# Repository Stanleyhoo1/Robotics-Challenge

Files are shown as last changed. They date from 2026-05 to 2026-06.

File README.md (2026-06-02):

# Robotics-Challenge

All active firmware lives in `main/`. Top-level companion folders:

| Folder | Purpose |
|---|---|
| `main/` | **Final firmware** — multi-file Arduino sketch |
| `docs/` | Software architecture diagrams and Mermaid flowcharts |
| `testing/` | Standalone test sketches (`line_following`, `motor_test`, `encoder_test`, `turn_test`, `junction_test`, `servo_motor`, `wifi`, `i2c_scan`) and the Testing & Calibration evidence PDF |
| `grid_nav_test/` | Integration test: line-zone grid navigation with RFID |
| `grid_nav_no_line_test/` | Integration test: no-line-zone dead-reckoning |
| `obstacle_avoid_test/` | Integration test: obstacle detection and A\* rerouting |
| `robot_revival_test/` | Integration test: multi-robot revival mechanic |
| `WallFollowing/` | Isolated wall-following development sketch |

## Repository structure

```
main/
├── main.ino           setup() / loop(); owns showIR, showDistance, showEncoders,
│                      showPitch, showLDR, isEnabled, useStateMachine,
│                      lastForwardDistanceCm; power-button + obstacle gates
├── config.h           tunable constants — pins, speeds, gains, thresholds,
│                      calibration values, airlock coords, line-zone split
├── globals.h          extern declarations for cross-.ino globals (one block per
│                      owning file)
├── types.h            enums (NavState, TagState, Facing, LineState,
│                      DistanceSensor) and structs (GridPos, FertileResult)
├── secrets.h          WiFi credentials, broker host/port, team id (gitignored)
├── commands.ino       handleSerialCommands; debug/test commands (nav, arena,
│                      stop, selftest, hop, enc, state, pos, tag, astar, target,
│                      calib, recalib, ldr, pitch)
├── distance.ino       HC-SR04 wrappers — getDistanceCM, readAndPrintDistance
├── ir_sensor.ino      9-element IR reflectance array, kvstore-backed calibration,
│                      LDR analog read
├── motors.ino         Motoron I2C drive, LSM6 IMU, turnDegrees, moveForward,
│                      2 quadrature encoders (BL + BR) with ISRs + counters,
│                      hop-heading lock, self-calibrating ticks/cm with KV persist
├── navigation.ino     Line-following, junction handling, A* planner, target
│                      selection, state-machine dispatcher (navigationUpdate)
│                      with tick functions, wall-follow, obstacle-avoid, base
│                      exit + return sequences, line-lost recovery
├── rfid.ino           MFRC522 setup; legacy rfidLoop (only runs when state
│                      machine is off)
├── servo.ino          servo sweep (planting actuator)
└── wifi.ino           MiniMessenger pub/sub, onMessage parser, send helpers,
                       heartbeat watchdog, status LED
```

## Required libraries

Install via Arduino IDE → Library Manager:

| Library | Purpose | 
|---|---|
| Motoron | I2C motor controller driver |
| LSM6 | 6-DOF IMU (gyro-only used) |
| MFRC522_I2C | RFID reader over I2C |
| MiniMessenger | WiFi pub/sub messaging |
| Servo | Servo driver |
| kvstore_global_api | Persistent KV storage (mbed) |

`kvstore_global_api` is part of the Arduino mbed core that's installed with the Giga board package. Installing the board (see below) brings it in automatically. `Servo` ships with the IDE. The other four need explicit installs.

## Setup

### 1. Install the board package
Arduino IDE → Boards Manager → search "Giga" → install **Arduino Mbed OS Giga Boards**.

### 2. Patch the Motoron library for mbed I2C

The stock Motoron library uses `TwoWire*` for its I2C bus type, which is incompatible with the Arduino Giga's mbed-based I2C stack. After installing the library, replace the `MotoronI2C` class in:

```
Documents/Arduino/libraries/Motoron/src/Motoron.h  (lines ~1923–2010)
```

with the mbed-compatible version below:

```cpp
class MotoronI2C : public MotoronBase
{
public:
  MotoronI2C(uint8_t address = 16, arduino::MbedI2C* wire = &Wire) : bus(wire), address(address) {}

  void setBus(arduino::MbedI2C * bus) { this->bus = bus; }
  arduino::MbedI2C * getBus() { return this->bus; }
  void setAddress(uint8_t address) { this->address = address; }
  uint8_t getAddress() { return address; }

private:
  arduino::MbedI2C * bus;
  uint8_t address;

  void sendCommandCore(uint8_t length, const uint8_t * cmd, bool sendCrc) override
  {
    bus->beginTransmission(address);
    for (uint8_t i = 0; i < length; i++) { bus->write(cmd[i]); }
    if (sendCrc) { bus->write(calculateCrc(length, cmd)); }
    lastError = bus->endTransmission();
  }

  void flushTransmission() { }

  void readResponse(uint8_t length, uint8_t * response) override
  {
    bool crcEnabled = protocolOptions & (1 << MOTORON_PROTOCOL_OPTION_CRC_FOR_RESPONSES);
    uint8_t byteCount = bus->requestFrom(address, (uint8_t)(length + crcEnabled));
    if (byteCount != length + crcEnabled)
    {
      memset(response, 0, length);
      lastError = 50;
      return;
    }
    lastError = 0;
    uint8_t * ptr = response;
    for (uint8_t i = 0; i < length; i++) { *ptr = bus->read(); ptr++; }
    if (crcEnabled && bus->read() != calculateCrc(length, response))
    {
      lastError = 51;
      return;
    }
  }
};
```

This patch is required to pass `Wire1` (a `arduino::MbedI2C` object) to the Motoron constructor. Without it, the firmware will not compile on the Giga.

### 3. Create `main/secrets.h`
This file is gitignored and must be created locally. Template:

```cpp
#pragma once
#define WIFI_SSID      "your-ssid"
#define WIFI_PASSWORD  "your-password"
#define BROKER_HOST    "broker.local"
#define BROKER_PORT    1883
#define GROUP_ID       "your-team-id"
```

### 4. First-boot calibration
Two things calibrate at boot:

- **Gyro bias** — robot must be motionless for ~2 seconds during boot. The Serial monitor will print "Calibrating gyro, keep still..." followed by "Gyro calibrated." Don't bump the chassis during this window.
- **IR sensor min/max** — only needed once. Hold the robot over the line, open the Serial monitor, send the `c` command. You have 10 seconds to slide the array fully across the line. Values are persisted in flash via `kvstore_global_api`, so subsequent boots reuse them.
- **Encoder ticks/cm** — self-calibrates at run time from confirmed straight tag-to-tag hops once the bot is in the arena. Until `CALIB_MIN_SAMPLES` (4) accepted samples land, `TICKS_PER_CM_FALLBACK` is used. Calibration is persisted in KV — use the `recalib` serial command to wipe and re-acquire.

### 5. I2C bus order
`setup()` calls `Wire.begin()` then `Wire1.begin()`. `Wire` carries the RFID reader (default I2C pins, address 0x28); `Wire1` carries the Motoron motor controller (address 16) and the LSM6 IMU. Both buses must be initialized before any device on them is touched.

## Upload

1. Connect the Giga over USB.
2. Arduino IDE → Select Board → **Arduino Giga R1 WiFi**.
3. Check the port to make sure it is correct (e.g. `COM5` on Windows, `/dev/ttyACM0` on Linux, `/dev/cu.usbmodem...` on macOS).
4. Open `main/main.ino` — the IDE will load the whole multi-file sketch from that directory.
5. Click Upload.

The first compile pulls in all the libraries above; expect ~30 s. Subsequent builds are fast.

## Starting a run

1. Power on. Boot prints land on Serial at 115200 baud.
2. Wait for `Gyro calibrated.` and `WiFi connecting...`.
3. The LED blinks red while disabled (no heartbeat / button off).
4. Press the **power button** (pin 17) — the LED goes solid red and the state machine starts executing whatever state it was last in (default `NAV_BASE_TO_FIRST_JUNCTION`). The state is preserved across disable/re-enable cycles, so if the bot gets disabled mid-run it resumes from where it stopped.
5. Holding either **revive button** (52 or 53) overrides the LED to green for the duration. Useful as a visual sanity check that the green channel works.

## Serial commands

Open the Serial monitor at **115200 baud**, line ending = Newline. Commands are case-insensitive. These were used for debugging and isolating features to test.

### Movement
| Command | Effect |
|---|---|
| `<number>` | Turn that many degrees via gyro (e.g. `90`, `-45`) |
| `forward` | Drive forward 3 s at `FORWARD_SPEED` |
| `forward <speed>` | Drive forward 3 s at the given Motoron speed |
| `hop` | One heading-locked hop until `nearNextNode()` (≤10 s)  |
| `stop` | Zero motors + `isEnabled = false` |

### Sensors / calibration
| Command | Effect |
|---|---|
| `ir` | Toggle IR readings printout |
| `distance` | Toggle forward-ultrasonic readings printout |
| `sensors`  | Toggle both `ir` and `distance` together |
| `enc` | Toggle 5 Hz encoder counter printout |
| `encreset` | Zero both encoder counters |
| `ldr` | Toggle 5 Hz LDR (light sensor) printout |
| `pitch` | Toggle 5 Hz IMU pitch printout (ramp detection) |
| `c` | Recalibrate IR sensors (10 s window) |
| `calib` | Print current encoder calibration state |
| `recalib`  | Wipe persisted encoder calibration from KV |

### State machine
| Command | Effect |
|---|---|
| `nav` | Toggle state machine (sets `NAV_BASE_TO_FIRST_JUNCTION` on) |
| `arena` | Jump straight to `NAV_ARENA_NAV` (skip base exit, bench tests)  |
| `state` | Dump `navState`, `robotPos`, `robotFacing`, seedsRemaining etc. |
| `pos <r> <c> <n\|e\|s\|w>` | Force `robotPos` and `robotFacing` |
| `tag <r> <c> <u\|f\|i\|p\|b>` | Set `tagMap[r][c]` cell state (b = BLOCKED for A\* obstacle) |
| `target` | Print `selectNextTarget` result |
| `astar <r1> <c1> <r2> <c2>` | Print A\* first step for the given pair |
| `selftest` | Run hardcoded assertions on the pure-logic code |

### Server passthrough
Anything not matched above is forwarded verbatim to the server via WiFi (to test robot -> server requests and responses).

## Status LED

The RGB status LED on pins 48 (R) and 49 (G) reflects a small priority stack:

| Color | Condition |
|---|---|
| **Green** | Either revive button (52/53) held — overrides everything else |
| **Solid red** | `isEnabled` true |
| **Blinking red** | `isEnabled` false; awaiting button press / server heartbeat |

## Algorithm overview

### Line-following PID

`followLineBase()` reads the 9-element IR array and computes a weighted-average position (`avg/sum`, scaled 0–8000). Error = `LINE_CENTER − position`. A proportional correction (`KP × error`) is added to the left wheel and subtracted from the right wheel. Raw PWM is sent directly (no voltage scaling) with a ±800 clamp so the slow wheel can reverse on tight bends. When `sum < IR_MIN_LINE_SUM` (no line under the array), motors are zeroed rather than holding the last PWM — this prevents the robot from drifting past a line end.

### A\* path planner

`aStarNextStep()` runs A\* on the 9×9 grid using Manhattan distance as the heuristic and unit edge costs. All scratch arrays are static (no heap allocation). `TAG_BLOCKED` cells are skipped as neighbours. On each call it returns only the first step of the optimal path, so target selection and replanning happen every node rather than committing to a full route. `selectNextTarget()` picks the nearest cell by tier: `TAG_FERTILE` > `TAG_UNKNOWN` > skip (`TAG_INFERTILE` / `TAG_PLANTED` / `TAG_BLOCKED`). Once seeds are exhausted, the target locks to Airlock B until the robot parks.

### Gyro-based turning

`turnDegrees()` integrates the LSM6 gyro's Z-axis rate (biased subtracted, scaled to °/s) until the accumulated angle reaches the target. Per-direction speed constants (`{RIGHT,LEFT}_TURN_{FORWARD,BACKWARD}_SPEED`) compensate for motor asymmetry. A per-direction early-stop trim (`{RIGHT,LEFT}_TURN_TRIM_DEG`) prevents the gyro-coast overshoot one direction experiences. An early-exit on `sum >= IR_MIN_LINE_SUM` (line centred under array, after a grace rotation) lets the line snap the robot onto the new lane precisely without over-rotating.

### Dead-reckoning in the no-line zone

In rows 0–3 (no guidance lines), the robot drives forward using encoder tick counts and gyro heading-lock. `hopDistanceCm() = straightTicks() / calibTicksPerCm` tracks travel distance. `applyHeadingCorrection()` applies a P-controller on the accumulated heading error to keep the robot straight. Arrival is detected at 85% of `GRID_SPACING_CM` to leave deceleration room. Any drift is corrected at the next RFID fix, which overwrites the estimated position with the server-confirmed ground-truth coordinate.

### Self-calibrating encoder ticks/cm

`calibRecordHop()` accepts every confirmed straight RFID-to-RFID hop (Manhattan distance 1) and computes `ticks / GRID_SPACING_CM`. Outliers more than 20% from the running mean are rejected. After 4 accepted samples the estimate locks and is persisted to KV flash so it survives reboots. Before lock, a hard-coded fallback (`TICKS_PER_CM_FALLBACK = 159.97`) is used.

### Tunnel wall-following (PID)

`wallFollow()` centres the robot between the tunnel walls by minimising `leftDist − rightDist`. A PID controller (KP=25, KI=8, KD=50) drives a differential speed correction. Both sides are EMA-smoothed (α=0.25) to filter ultrasonic noise. Anti-windup prevents integrator blow-up: the integrator only accumulates when the correction is not already saturated in the same sign. Exit condition is the IR array seeing a line — the robot has exited the tunnel.

### Safety architecture

`isEnabled` is the master gate. It is set by server heartbeats and cleared on timeout, `type=disable`/`type=emergency`, or power-button press. The gate is checked at the top of every `loop()` tick and inside every blocking action (turn, nudge, recovery). A heartbeat timeout only triggers once the server has sent at least one heartbeat, so bench-testing without a server never trips the timeout.

## Further reading

- `docs/software_overview.md` — block diagram of the firmware architecture.
- `docs/flowcharts.md` — Mermaid flowcharts for all main robot behaviours (line-following, RFID/planting, kill-switch, base exit, arena nav, line-lost recovery, return sequence, obstacle avoidance, encoder calibration).

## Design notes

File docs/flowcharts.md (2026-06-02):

# Flowcharts

Mermaid diagrams for the key control flows. They render on GitHub, GitLab, and most markdown viewers with Mermaid support; the raw source is still readable as plain text otherwise.

## 1. Line following

`followLineBase()` is the line-follow tick used inside the base and in the line zone of the arena (rows 4–8).

```mermaid
flowchart TD
    A["followLineBase called"] --> B["read IR array"]
    B --> C{"line under array?"}
    C -->|yes| D["PID correction<br/>drive motors"]
    C -->|no| E["stop motors"]
    D --> F["return LineState"]
    E --> F
    F --> G{"LineState?"}
    G -->|JUNCTION| H["transition to turn state"]
    G -->|LINE_LOST<br/>unexpected| I["baseLineLostRecovery"]
    G -->|LINE_LOST<br/>expected end| J["next state<br/>(pause / park)"]
    G -->|LINE_NORMAL| K["continue"]
```

Key behaviors:
- When the line is lost, motors are zeroed instead of holding the last PWM. Prevents drift past the line end.
- `LINE_FOLLOW_MIN_SPEED` is the floor for the slow-wheel side of the PID — below it the motor stalls and just buzzes.

## 2. RFID + planting decision

Runs on every arena tick. Scan the tag, ask the server what it is, act on the answer.

```mermaid
flowchart TD
    A["scan RFID"] --> B{"tag found?"}
    B -->|no| C["keep driving"]
    B -->|yes| D{"in base?"}
    D -->|yes| E["request airlock A (outbound)<br/>or B (returning)"]
    D -->|no| F["request fertility"]
    F --> G["update map:<br/>fertile / infertile / planted"]
    G --> H{"fertile and not planted<br/>and seeds left?"}
    H -->|yes| I["plant seed<br/>mark planted on map"]
    H -->|no| J["pick next target<br/>from map"]
    I --> J
    J --> C
```

Notes:
- "Pick next target" prioritizes fertile-unplanted, then unknown, then everything else, by Manhattan distance.
- Once seeds are exhausted, the next target becomes airlock B (return path).

## 3. Emergency / kill switch

Four independent triggers can pause or stop the robot.

```mermaid
flowchart TD
    T1["heartbeat timeout"] --> U["isEnabled = false"]
    T2["server: emergency / disable"] --> U
    T3["power button"] --> U
    T4["forward obstacle"] --> V["stop motors this tick"]
    U --> W["safety gate:<br/>stop motors<br/>preserve navState"]
    W --> X{"isEnabled again?"}
    X -->|no| W
    X -->|yes| Y["resume same state"]
    V --> Z{"obstacle cleared?"}
    Z -->|no| V
    Z -->|yes| AA["resume same state"]
```

Behavioral split:
- An `isEnabled` drop **does not change `navState`**. Re-enable resumes whatever state was active before the pause.
- A forward obstacle auto-resumes the moment the obstacle clears (door opens / object moved).
- `NAV_BASE_RETURN` is special-cased in the obstacle gate: hitting something in front while returning ends the run.

## 4. Base exit sequence

From boot to arena nav. Three junctions are traversed before entering the tunnel.

```mermaid
flowchart TD
    A["boot: disabled"] --> B["power button press"]
    B --> C["follow line"]
    C --> D{"junction?"}
    D -->|no| C
    D -->|yes| E["turn +90° (1st junction)"]
    E --> F["follow line + RFID poll"]
    F --> G{"RFID hit?"}
    G -->|no| F
    G -->|yes| H["request airlock A"]
    H --> I{"clearance?"}
    I -->|no| I
    I -->|yes| J["follow line"]
    J --> K{"junction?"}
    K -->|no| J
    K -->|yes| L["turn -90° (2nd junction)"]
    L --> M["follow line"]
    M --> N{"junction?"}
    N -->|no| M
    N -->|yes| O["turn ±90° (3rd junction)"]
    O --> P["follow line until line lost"]
    P --> Q{"line lost?"}
    Q -->|no| P
    Q -->|yes| R["pause, then nudge forward into tunnel"]
    R --> S["wall-follow through Tunnel A"]
    S --> T{"IR sees line?"}
    T -->|no| S
    T -->|yes| U["seed position = Airlock A<br/>enter arena nav"]
```

## 5. Line-lost recovery (base only)

Triggered when `followLineBase()` returns `LINE_LOST` in a state where the line is *not* expected to end.

```mermaid
flowchart TD
    A["nudge forward 5 cm"] --> B{"line under array?"}
    B -->|yes| C["return success"]
    B -->|no| D["sweep left 90°"]
    D --> E{"line found?"}
    E -->|yes| C
    E -->|no| F["sweep right 180°"]
    F --> G{"line found?"}
    G -->|yes| C
    G -->|no| H["recenter<br/>return failure"]
    H --> I["caller: park"]
```

Total angular search range is ±90° from start. Each sweep stops the instant a line appears.

## 6. Status LED priority stack

`updateLED()` runs every tick.

```mermaid
flowchart TD
    A["updateLED"] --> B{"revive button pressed?"}
    B -->|yes| C["solid green"]
    B -->|no| D{"isEnabled?"}
    D -->|yes| E["solid red"]
    D -->|no| F["blink red"]
```

Revive buttons are the only override. Otherwise the LED is solid red while enabled and blinks red while disabled.

## 7. Return-to-base sequence

After the last seed is planted, the planner targets airlock B and the run reverses.

```mermaid
flowchart TD
    A["last seed planted"] --> B["target = airlock B"]
    B --> C["arena nav"]
    C --> D{"at airlock B?"}
    D -->|no| C
    D -->|yes| E["rotate to face base"]
    E --> F["request airlock B"]
    F --> G{"clearance?"}
    G -->|no| G
    G -->|yes| H["wall-follow through Tunnel B"]
    H --> I{"IR sees line?"}
    I -->|no| H
    I -->|yes| J["follow line"]
    J --> K{"line ended<br/>or obstacle?"}
    K -->|no| J
    K -->|yes| L["parked"]
```

Notes:
- Door-open detection in both tunnels watches the forward ultrasonic, not the clearance message. Clearance is for verification only.
- `BASE_RETURN` ends on whichever happens first: the line ending naturally, or an obstacle in front.

## 8. Junction handling (legacy)

`handleJunction()` is only used by the legacy `NAV_LINE_FOLLOW` test path. The state-machine path uses `baseTurnBlocking()` for base junctions and `NAV_POST_TAG_NUDGE` for arena turns instead — both are simpler and don't go through this function.

```mermaid
flowchart TD
    A["handleJunction"] --> B{"already in junction?"}
    B -->|yes| C["return"]
    B -->|no| D["drive past junction centre"]
    D --> E{"action = straight?"}
    E -->|yes| F["skip spin"]
    E -->|no| G["spin until line reappears"]
    F --> H["bump KP to aggressive<br/>exit junction"]
    G --> H
```

Kept for the test-mode path and for reference; production base-exit and arena flows do not use it.

## 9. Arena navigation tick

`navArenaTick()` runs each loop iteration while in `NAV_ARENA_NAV`. The zone (line vs. no-line) determines the locomotion sub-system; RFID is always the position truth.

```mermaid
flowchart TD
    A["navArenaTick"] --> B{"returning AND<br/>at Airlock B?"}
    B -->|yes| C["stop → NAV_AT_AIRLOCK_B"]
    B -->|no| D{"forward obstacle<br/>< OBSTACLE_AVOID_CM?"}
    D -->|yes| E["stop → NAV_AVOID_OBSTACLE"]
    D -->|no| F["poll RFID"]
    F --> G{"tag detected?"}
    G -->|yes| H["stop motors<br/>sendIsFertile<br/>→ NAV_AT_TAG"]
    G -->|no| I{"row ≥ LINE_ZONE_MIN_ROW?"}
    I -->|yes (line zone)| J["followLineBase PID<br/>IR guides steering"]
    I -->|no (no-line zone)| K{"dead-reckon<br/>driving?"}
    K -->|no| L["reset encoders + heading<br/>start motors → driving=true"]
    K -->|yes| M["applyHeadingCorrection"]
    M --> N{"nearNextNode?<br/>(encoder ≥ 85 % of cell)"}
    N -->|no| A
    N -->|yes| O["stop, advance robotPos<br/>log rfid_miss_dead_reckon_advance"]
    J --> A
    O --> A
```

## 10. Obstacle avoidance

`navAvoidObstacleTick()` runs once per `NAV_AVOID_OBSTACLE` entry. It marks the blocked cell in the grid map so A\* reroutes around it automatically on the next replan.

```mermaid
flowchart TD
    A["NAV_AVOID_OBSTACLE entered"] --> B{"forward dist<br/>< CRASH_STOP_CM?"}
    B -->|yes| C["reverse CRASH_BACKUP_CM"]
    B -->|no| D["compute blocked cell<br/>= robotPos + facing"]
    C --> D
    D --> E{"cell in grid?"}
    E -->|yes| F["tagMap[cell] = TAG_BLOCKED"]
    E -->|no| G["skip — off-grid"]
    F --> H["replanNextDir()<br/>(A* skips BLOCKED cells)"]
    G --> H
    H --> I{"pendingJunctionDir != 0?"}
    I -->|no| J["no detour — back to NAV_ARENA_NAV"]
    I -->|yes| K["turnDegrees(dir × 90°)"]
    K --> L["update robotFacing"]
    L --> M["→ NAV_ARENA_NAV<br/>(A* now routes around obstacle)"]
```

## 11. Self-calibrating encoder ticks/cm

Every confirmed straight tag-to-tag hop feeds the calibration accumulator. Dead-reckoning accuracy improves with each sample and locks after `CALIB_MIN_SAMPLES` (4) accepted samples.

```mermaid
flowchart TD
    A["RFID fix at new cell"] --> B{"Manhattan distance<br/>from prev fix == 1?"}
    B -->|no| C["discard — not a clean 1-cell hop"]
    B -->|yes| D["candidate = straightTicks / GRID_SPACING_CM"]
    D --> E{"calibSamples > 0?"}
    E -->|yes| F{"|candidate - mean| / mean<br/>> CALIB_OUTLIER_PCT (20%)?"}
    F -->|yes| C
    F -->|no| G["accept sample"]
    E -->|no| G
    G --> H["calibSamples++<br/>calibSum += candidate"]
    H --> I{"calibSamples ≥<br/>CALIB_MIN_SAMPLES (4)?"}
    I -->|no| J["use TICKS_PER_CM_FALLBACK<br/>for current hops"]
    I -->|yes| K["lock: calibTicksPerCm = calibSum/n<br/>save to KV flash<br/>sendStatus(calib_locked)"]
```

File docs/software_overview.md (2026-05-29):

# Software overview

Text-based block diagram of the firmware. Arrows mean "calls" or "delegates to". Italics in the boxes are the file each function lives in.

## Top-level loop

`main.ino`'s `loop()` always runs the housekeeping pass, then runs the safety gate, then dispatches to the state machine (or legacy path when `useStateMachine` is false). `useStateMachine` defaults to **true** on boot.

```
                                main.ino — loop()
                                       │
                                       ▼
                  ── top-of-loop obstacle gate ──
                  getDistanceCM(SENSOR_FORWARD)
                  2-consecutive-readings debounce
                  rising edge → sendStatus("obstacle_stop")
                  falling edge → sendStatus("obstacle_cleared")
                  if NAV_WALL_FOLLOW / TUNNEL_B_WALL_FOLLOW
                    and door still closed:
                    every DOOR_RETRY_INTERVAL_MS resend
                    openAirlockA/B
                                       │
                                       ▼
        ┌──────────────────────────────┼──────────────────────────────┐
        │                              │                              │
   wifiLoop()                  checkPowerButton()             handleSerialCommands()
   (wifi.ino)                  (main.ino)                     (commands.ino)
        │                              │                              │
        │                  HIGH→LOW edge on pin 17                    │
        │                  toggles isEnabled                          │
        │                  (200 ms debounce)                          │
        │                                                             │
   ┌────┴───────┐                                                     │
   │            │                                                     │
onMessage   updateLED                                                 │
parser     priority stack:                                            │
   │       1. revive btn → green                                      │
   │       2. isEnabled  → solid red                                  │
isEnabled  3. else       → blink red                                  │
heartbeat                                                             │
fertileResult                                                         │
exit/enterClearance                                                   │
   │                                                                  │
   ▼                                                                  ▼
heartbeat watchdog:                                              test commands
if lastHeartbeatMs != 0                                          (nav, arena, stop,
   and millis - last > 1 s:                                       enc, hop, selftest,
   isEnabled = false                                              state, ldr, pitch,
                                                                  recalib, etc.)
                                       │
                          updateEncoders + updateHopHeading
                          readAndPrintIR / Distance / Encoders /
                                       Pitch / LDR
                                       │
                          ┌────────────┴────────────────┐
                          ▼                             ▼
              ── safety gate ──             ── enabled body ──
              if !isEnabled:                if useStateMachine:
                motors = 0                    navigationUpdate()
                handleNavDisable()          else:
                  (preserves navState!)       rfidLoop() +
                return                        applyMotorEnabled()
              if obstacleNow:                  [legacy path]
                motors = 0
                if NAV_BASE_RETURN:
                  → NAV_PARKED
                  sendStatus("parked_obstacle")
                return
```

Key invariants:
- `handleNavDisable` does **not** mutate `navState`. Re-enable resumes whatever state was active when the bot was disabled — the operator can disable mid-run with the button and resume from the same spot.
- The forward-obstacle gate only pauses motion for the tick; it doesn't change state. Auto-resume on the same tick that `stableObstacle` flips back to false (door opens, robot moves, object cleared).
- Heartbeat timeout only fires once at least one heartbeat has been received — bench-testing without a server doesn't trip it.

## State-machine dispatcher

`navigationUpdate()` switches on `navState` and dispatches to a per-state tick. Transitions happen inside each tick. The dispatcher prints `[NAV] -> NAME :: activity` once per state entry so the serial log reads as a play-by-play.

```
                navigationUpdate()  (navigation.ino)
                        │
                        ▼
              defense-in-depth: if !isEnabled, hold + return
                        │
                        ▼
              if state changed since last tick:
                Serial.print "[NAV] -> NAME :: activity"
                        │
                        ▼
                    switch(navState)
                        │
   ┌─── BASE-EXIT SEQUENCE ───────────────────────────────────────────────────┐
   │                                                                         │
   │  NAV_BASE_TO_FIRST_JUNCTION  →  followLineBase()                        │
   │     LINE_JUNCTION_*  → NAV_BASE_FIRST_TURN                              │
   │     LINE_LOST        → baseLineLostRecovery (nudge + ±90° sweep)        │
   │                                                                         │
   │  NAV_BASE_FIRST_TURN         →  baseTurnBlocking(+90°)                  │
   │     pre-turn nudge POST_TAG_FORWARD_CM (encoder)                        │
   │     turnDegrees → post-turn JUNCTION_NUDGE_MS forward kick              │
   │     → NAV_BASE_TO_TAG                                                   │
   │                                                                         │
   │  NAV_BASE_TO_TAG             →  followLineBase + readRfidNonBlocking    │
   │     RFID hit → sendOpenAirlockA → NAV_WAIT_EXIT_CLEARANCE               │
   │     LINE_LOST → recovery                                                │
   │                                                                         │
   │  NAV_WAIT_EXIT_CLEARANCE     →  hold + wifiPoll                         │
   │     exitClearance recvd → NAV_BASE_TO_SECOND_JUNCTION                   │
   │     timeout → resend openAirlockA every DOOR_RETRY_INTERVAL_MS          │
   │                                                                         │
   │  NAV_BASE_TO_SECOND_JUNCTION →  followLineBase()                        │
   │     LINE_JUNCTION_* → NAV_BASE_SECOND_TURN                              │
   │     LINE_LOST       → recovery                                          │
   │                                                                         │
   │  NAV_BASE_SECOND_TURN        →  baseTurnBlocking(-90°)                  │
   │     → NAV_BASE_TO_LINE_LOST                                             │
   │                                                                         │
   │  NAV_BASE_TO_LINE_LOST       →  followLineBase()                        │
   │     LINE_LOST       → NAV_BASE_LINE_LOST_PAUSE                          │
   │                                                                         │
   │  NAV_BASE_LINE_LOST_PAUSE    →  motors = 0, momentary hold              │
   │     hold BASE_LINE_LOST_PAUSE_MS → NAV_BASE_FORWARD_NUDGE               │
   │                                                                         │
   │  NAV_BASE_FORWARD_NUDGE      →  delay BASE_FORWARD_NUDGE_MS forward     │
   │     → NAV_WALL_FOLLOW                                                   │
   │                                                                         │
   │  NAV_WALL_FOLLOW             →  wallFollow() through Tunnel A           │
   │     IR sees line → seed robotPos = Airlock A → NAV_ARENA_NAV            │
   │                                                                         │
   └─────────────────────────────────────────────────────────────────────────┘

   ┌─── ARENA NAVIGATION ────────────────────────────────────────────────────┐
   │                                                                         │
   │  NAV_ARENA_NAV               →  navArenaTick()                          │
   │     RFID hit         → NAV_AT_TAG                                       │
   │     obstacle < 20cm  → NAV_AVOID_OBSTACLE                               │
   │     in line zone (row ≥ LINE_ZONE_MIN_ROW=4) → followLineBase           │
   │     in no-line zone → encoder hop + heading lock; nearNextNode → step   │
   │                                                                         │
   │  NAV_AT_TAG                  →  wait for isFertileReply                 │
   │     reply → update tagMap, robotPos                                     │
   │           if fertile + unplanted + seeds>0 → NAV_POST_TAG_NUDGE (plant) │
   │           else → replan; turn-needed → NAV_POST_TAG_NUDGE; else ARENA   │
   │                                                                         │
   │  NAV_POST_TAG_NUDGE          →  encoder-driven 5cm nudge                │
   │     intent=plant → NAV_PLANTING                                         │
   │     intent=turn  → turnDegrees(pendingJunctionDir × 90°), → ARENA_NAV   │
   │                                                                         │
   │  NAV_PLANTING                →  sweepTo MAX→MIN + MIN→MAX               │
   │     sendPlanted, seedsRemaining--                                       │
   │     seedsRemaining==0 → returning=true (target=Airlock B)               │
   │     replan + turn → NAV_ARENA_NAV                                       │
   │                                                                         │
   │  NAV_AVOID_OBSTACLE          →  mark cell TAG_BLOCKED, replan, turn     │
   │     → NAV_ARENA_NAV (A* now routes around the marked cell)              │
   │                                                                         │
   └─────────────────────────────────────────────────────────────────────────┘

   ┌─── RETURN SEQUENCE ─────────────────────────────────────────────────────┐
   │                                                                         │
   │  NAV_AT_AIRLOCK_B            →  rotate to face base, sendOpenAirlockB   │
   │     → NAV_WAIT_ENTER_CLEARANCE                                          │
   │                                                                         │
   │  NAV_WAIT_ENTER_CLEARANCE    →  hold + wifiPoll                         │
   │     enterClearance → NAV_TUNNEL_B_WALL_FOLLOW                           │
   │     timeout → resend openAirlockB                                       │
   │                                                                         │
   │  NAV_TUNNEL_B_WALL_FOLLOW    →  wallFollow() through Tunnel B           │
   │     IR sees line → NAV_BASE_RETURN                                      │
   │                                                                         │
   │  NAV_BASE_RETURN             →  followLineBase()                        │
   │     LINE_LOST → sendStatus("parked_line_end") → NAV_PARKED              │
   │     obstacle (top-of-loop) → sendStatus("parked_obstacle") → NAV_PARKED │
   │                                                                         │
   │  NAV_PARKED                  →  motors = 0, hold                        │
   │                                                                         │
   └─────────────────────────────────────────────────────────────────────────┘
```

## Arena navigation tick

`navArenaTick` runs different sub-logic for the line-zone (bottom rows 4–8, lines connect holes) vs. the no-line zone (top rows 0–3, holes only). **Note this is a ROW split**, not a column split (an earlier draft of the docs had it wrong).

```
                          navArenaTick()
                                │
                  ┌─────────────┴───────────────────────────────────────┐
                  │                                                     │
        return-mode short-circuit:                          obstacle check:
        if returning && robotPos == AIRLOCK_B               lastForwardDistanceCm
        → stop, → NAV_AT_AIRLOCK_B                          < OBSTACLE_AVOID_CM (20 cm)?
                                                            yes → stop, → NAV_AVOID_OBSTACLE
                                │
                                ▼
                  pollRfidAndQueue()
                  PICC_IsNewCardPresent + ReadCardSerial
                                │
                  ┌─────────────┴─────────────┐
                  │                           │
              tag detected               no tag
                  │                           │
                  ▼                           ▼
        build UID + halt           if (robotPos.row >= LINE_ZONE_MIN_ROW):
        clearFertileResult           // line zone
        sendIsFertile                followLineBase()
        stop motors                  (PID lane-keeping; junction
        navState = NAV_AT_TAG         classifications are ignored —
                                      sensor averages back to centre)
                                   else:
                                     // no-line zone
                                     if (!deadReckonDriving):
                                       encoderResetHop, resetHopHeading
                                       motors = BASE_SPEED
                                       deadReckonDriving = true
                                     else:
                                       applyHeadingCorrection()
                                       if nearNextNode():
                                         stop, endHopHeading
                                         advancePosOneCell
                                         sendStatus("rfid_miss_dead_reckon_advance")
                                         if returning && AIRLOCK_B → NAV_AT_AIRLOCK_B
```

## Line-lost recovery (base only)

When `followLineBase()` returns `LINE_LOST` in `NAV_BASE_TO_FIRST_JUNCTION`, `NAV_BASE_TO_TAG`, or `NAV_BASE_TO_SECOND_JUNCTION`, the state's tick calls `baseLineLostRecovery()`:

```
        baseLineLostRecovery()  (blocking)
              │
              ▼
        1. Forward POST_TAG_FORWARD_CM via encoder hop
              │
              ▼
        2. readSensors → line under array? → yes, return true
              │
              ▼ no
        3. sweepForLine(-1, 90°)   ← sweep left up to 90°
              │
              ▼ no line
        4. sweepForLine(+1, 180°)  ← sweep right through centre to +90°
              │
              ▼ no line
        5. sweepForLine(-1, 90°)   ← re-centre, best-effort
              │
              ▼
        return false  → caller: sendStatus("base_recovery_failed"), → NAV_PARKED
```

Each sweep stops the instant `readSensors` shows `sum >= IR_MIN_LINE_SUM`. `wifiLoop()` runs every ~5 ms inside the blocking loops so the heartbeat survives.

`NAV_BASE_TO_LINE_LOST` (line ending at tunnel mouth) and `NAV_BASE_RETURN` (line ending at parking) do **not** use this recovery — losing the line in those states is the expected exit signal.

## Planner

```
        navAtTagTick fertile reply / navPlantingTick done / navAvoidObstacleTick done
              │
              ▼
        replanNextDir()
              │
       ┌──────┴──────┐
       │             │
   returning?     normal
       │             │
       ▼             ▼
   targetPos =    selectNextTarget(robotPos, targetPos)
   AIRLOCK_B      prioritise TAG_FERTILE > TAG_UNKNOWN
                  skip TAG_INFERTILE / TAG_PLANTED / TAG_BLOCKED
                  within tier: lowest Manhattan distance
                  │
                  ▼
              aStarNextStep(robotPos, targetPos, next)
              A* on 9×9 grid, Manhattan heuristic, unit edge costs
              skips TAG_BLOCKED cells, static scratch arrays
                  │
                  ▼
              facingToward(robotPos, next)
              getTurnDir(robotFacing, want)
                  │
                  ▼
              pendingJunctionDir ∈ {-1, 0, +1, 2}
              (consumed by NAV_POST_TAG_NUDGE / NAV_AVOID_OBSTACLE)
```

`returning` flips true once `seedsRemaining` hits 0 inside `navPlantingTick`. From then on, every replan targets Airlock B. `TAG_BLOCKED` cells (set by `NAV_AVOID_OBSTACLE`) are skipped by both `selectNextTarget` and the A* neighbour iteration, so a marked obstacle reroutes automatically.

## WiFi / messaging

```
        MiniMessenger (wifi.ino)
                │
   ┌────────────┴────────────────┐
   │                             │
incoming                     outgoing
   │                             │
   ▼                             ▼
onMessage(payload):       wifiSend(msg)
parses key=value           ↑
strings                    │
   │              ┌────────┴────────────────────────────────────┐
   │              │       │      │        │        │        │
   ▼          sendRegister sendIsFertile sendPlanted          │
matches:        sendPosition sendStatus sendOpenAirlockA      │
 type=heartbeat                          sendOpenAirlockB     │
   enable=1|0 → isEnabled
   refreshes lastHeartbeatMs
 type=emergency / disable → isEnabled = false
 type=exitClearance       → exitClearanceReceived = true
 type=enterClearance      → enterClearanceReceived = true
 type=isFertileReply      → fertileResult populated (received, fertile,
                            planted, tagId, x, y)
```

`wifiLoop()` runs:
1. `messenger.loop()`
2. `updateLED()` — applies the priority stack (revive → red enabled → blink red disabled)
3. Heartbeat watchdog: `lastHeartbeatMs != 0 && now - last > HEARTBEAT_TIMEOUT_MS` → `isEnabled = false`
4. Re-registration every `REGISTER_INTERVAL_MS` (10 s)

Door-open signal: the state machine watches the forward ultrasonic going back above `OBSTACLE_STOP_CM`, **not** the clearance messages. `exit/enterClearanceReceived` flags exist for verification/debug only — the gate retry loop in `main.ino` resends `openAirlockA/B` while the obstacle is still latched at a closed door.

## Encoder + hop-heading subsystem

Two quadrature encoders only — back left (BL) and back right (BR). Front encoders aren't wired. Each rear encoder uses two ISRs (one per channel) with full 4× quadrature decoding via `CHANGE` on both A and B.

```
   Hardware ISRs              Always-run in loop()              Consumers
   (motors.ino)               (main.ino)                        (navigation.ino,
                                                                 commands.ino)
   isr_BL_A  ─┐
   isr_BL_B   │  → encBL  → leftTicks()  ──┐                    │
   isr_BR_A   │                            │── straightTicks() ─→ hopDistanceCm()
   isr_BR_B  ─┘  → encBR  → rightTicks() ──┘                    │   nearNextNode()
                                                                 ─→ calibRecordHop()
                                                                    ticksPerCm lock
                                                                 │  (KV-persisted)
                          updateHopHeading()                     │
                          (no-op unless                          │
                           hopHeadingActive)                     │
                                  │                              │
                                  ▼                              │
                              hopHeadingDeg ─→ applyHeadingCorrection()
                                              motor differential
                                              while deadReckonDriving
```

`leftTicks() = encBL`, `rightTicks() = encBR` directly — no averaging needed with one encoder per side. `straightTicks() = (leftTicks() + rightTicks()) / 2`. The BL ISRs are sign-flipped so both sides report positive ticks for forward motion.

Self-calibrating `ticksPerCm`: every confirmed straight tag-to-tag hop in the arena feeds `calibRecordHop(prevPos, newPos)`. Manhattan-distance-1 samples are accepted; outliers (>20 % from running mean) are rejected. After `CALIB_MIN_SAMPLES` (4) accepted samples, the value locks and is persisted to KV. `recalib` clears it.

## Self-test (`selftest` command)

`runSelftest()` asserts on the pure-logic code (no hardware needed):
- `getTurnDir` / `facingAfterTurn` round-trips
- `facingToward` for cardinal neighbours
- `aStarNextStep` straight-line, around obstacles, no-path
- `selectNextTarget` priority order with mixed tag states
- `calibRecordHop` accept/reject paths
- LineState classification on synthetic IR buffers

Run after any change to the planner, calibration, or facing-math code.

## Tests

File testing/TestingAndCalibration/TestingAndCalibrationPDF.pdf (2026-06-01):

## 0.1 Testing Electronics

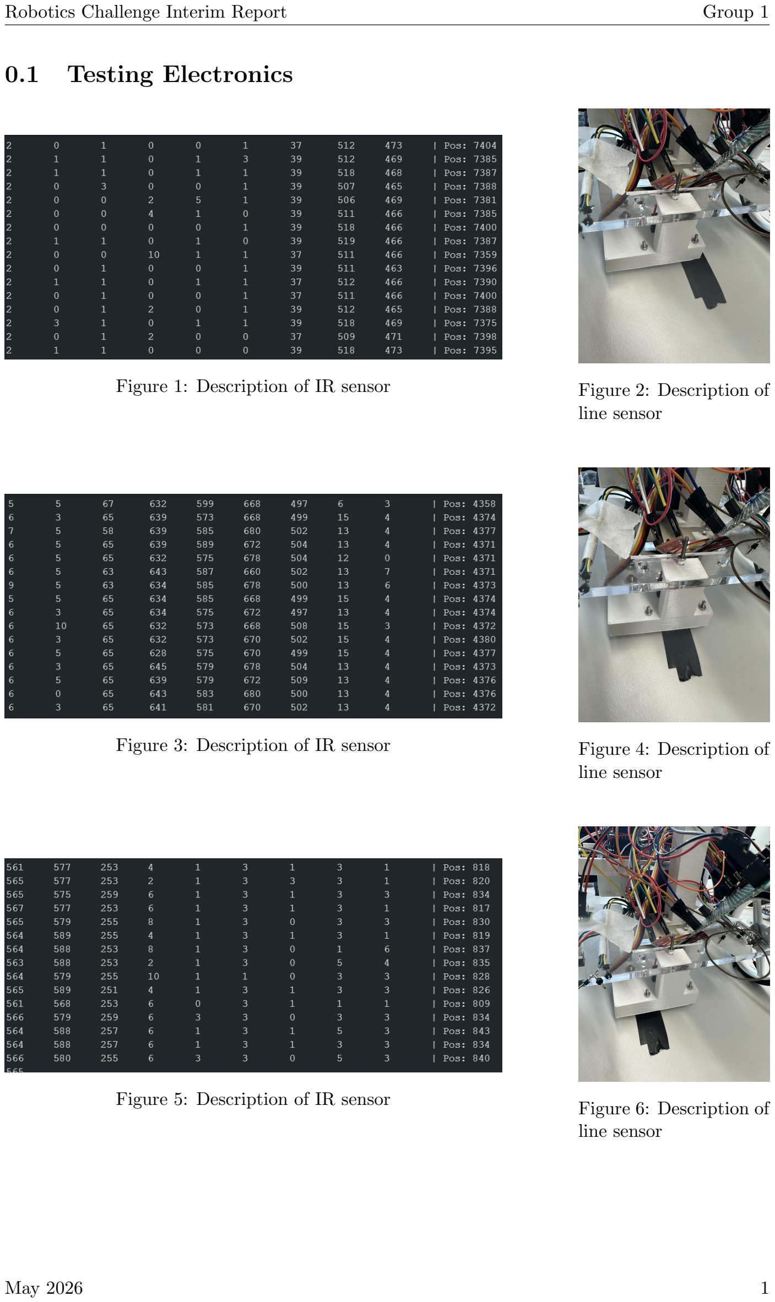
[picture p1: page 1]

Robotics Challenge Interim Report | Group 1
Figure 1: Description of IR sensor | Figure 2: Description of
| line sensor
Figure 3: Description of IR sensor | Figure 4: Description of
| line sensor
Figure 5: Description of IR sensor | Figure 6: Description of
| line sensor
May 2026 | 1

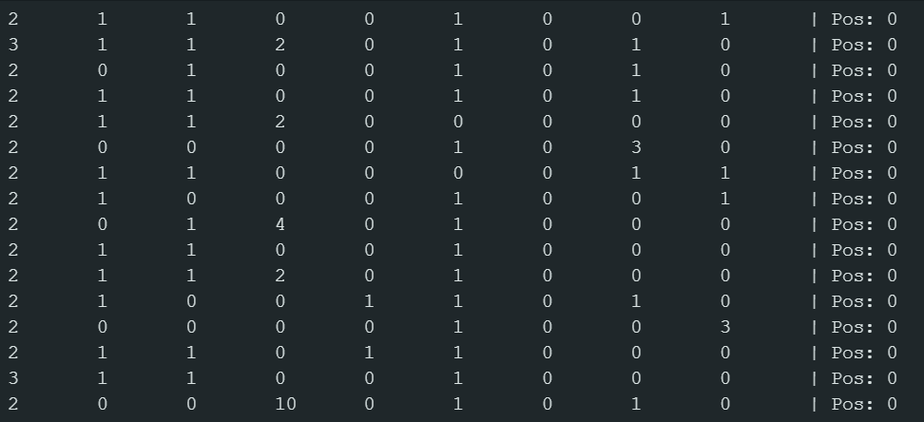
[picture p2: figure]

Figure 7: Description of IR sensor | Figure 8: Description of
| line sensor

Figure 9–12 show the sensor readings and corresponding robot position for four line configurations.

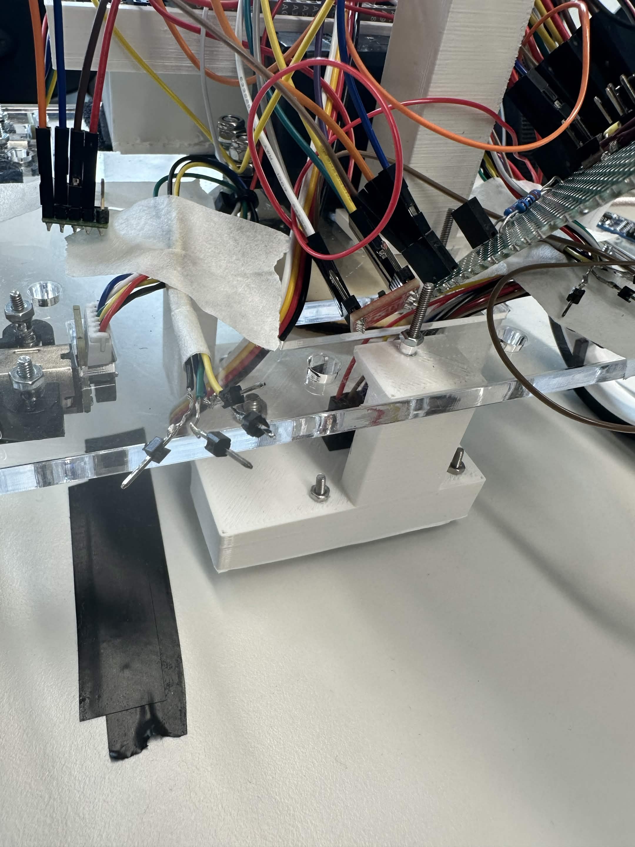
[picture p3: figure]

(a) Serial Monitor readings when off the line. | (b) Robot position when off the line.

Figure 9: Reflectance sensor readings and robot position: off the line.

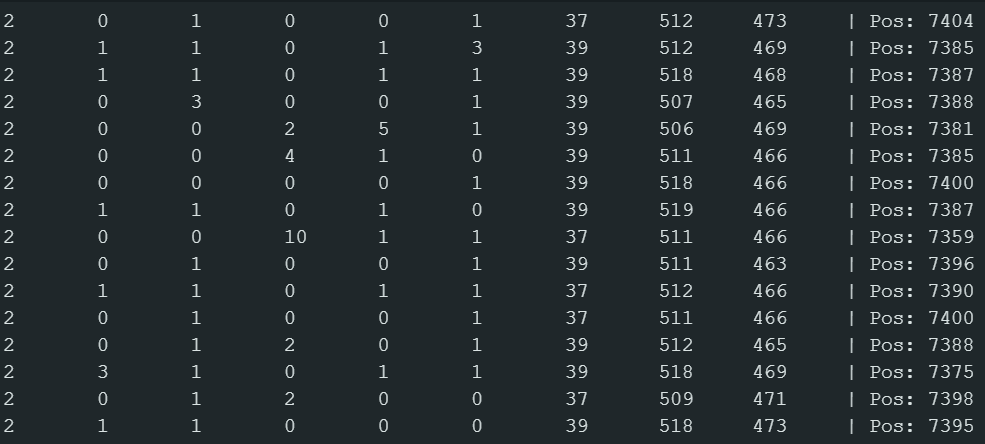
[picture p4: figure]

(a) Serial Monitor readings when left of the line. | (b) Robot position when left of the line.

Figure 10: Reflectance sensor readings and robot position: left of the line.

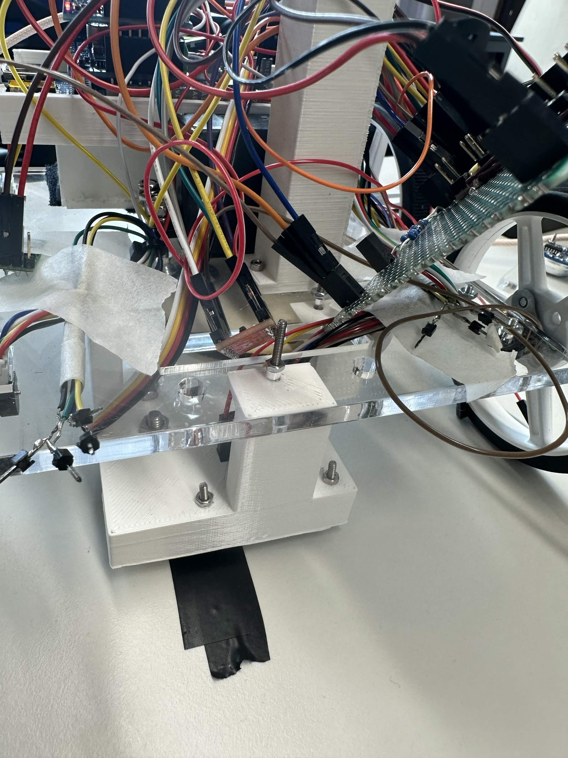
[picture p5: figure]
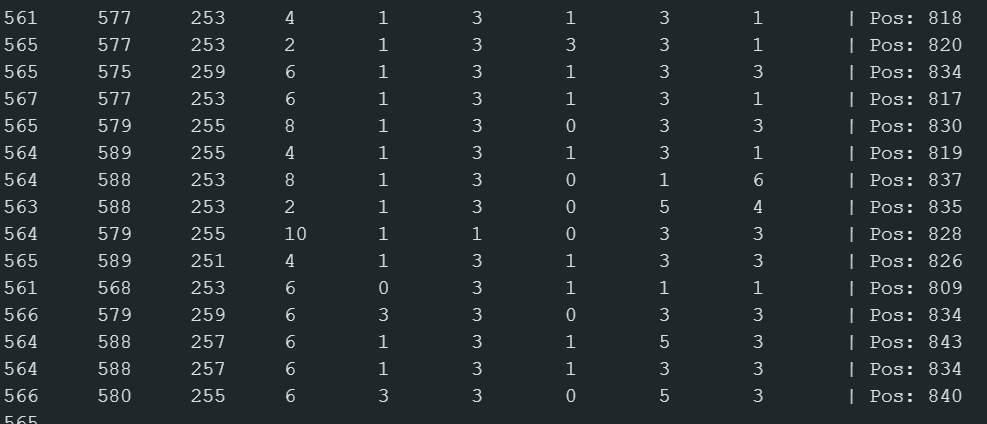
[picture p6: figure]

(a) Serial Monitor readings when right of the line. | (b) Robot position when right of the line.

Figure 11: Reflectance sensor readings and robot position: right of the line.

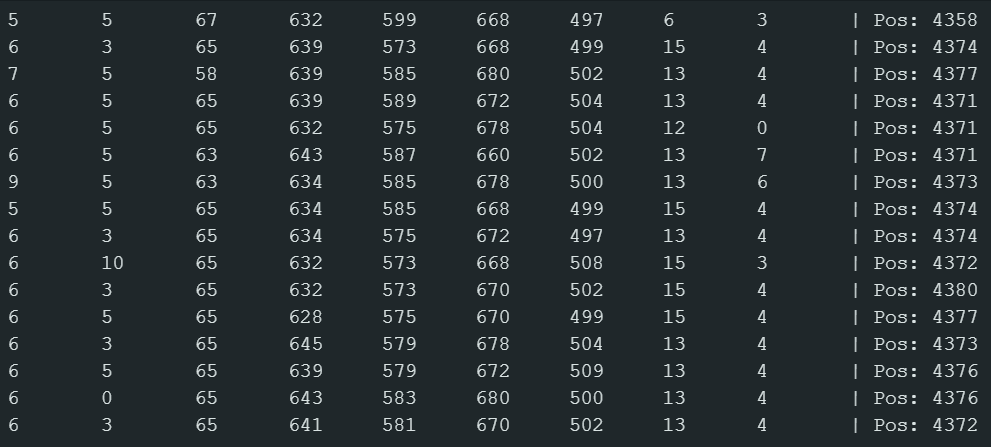
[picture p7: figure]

(a) Serial Monitor readings when centred on the
line.
(b) Robot position when centred on the line.

Figure 12: Reflectance sensor readings and robot position: centred on the line.

Figure 13 shows the HC-SR04 waveforms and a demonstration of live distance readings.

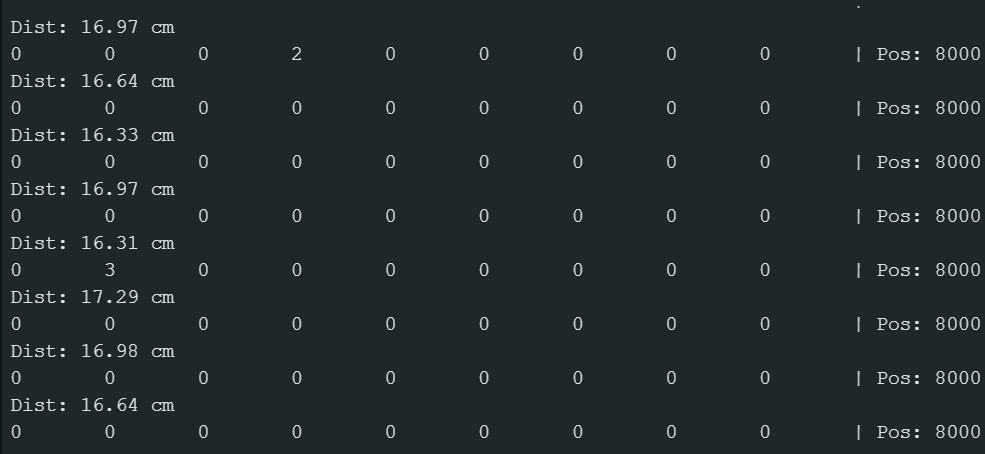
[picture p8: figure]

(a) HC-SR04 trigger and echo signal waveforms. | (b) Live distance readings from the sensor.

Figure 13: HC-SR04 ultrasonic sensor signals and distance measurement demo.

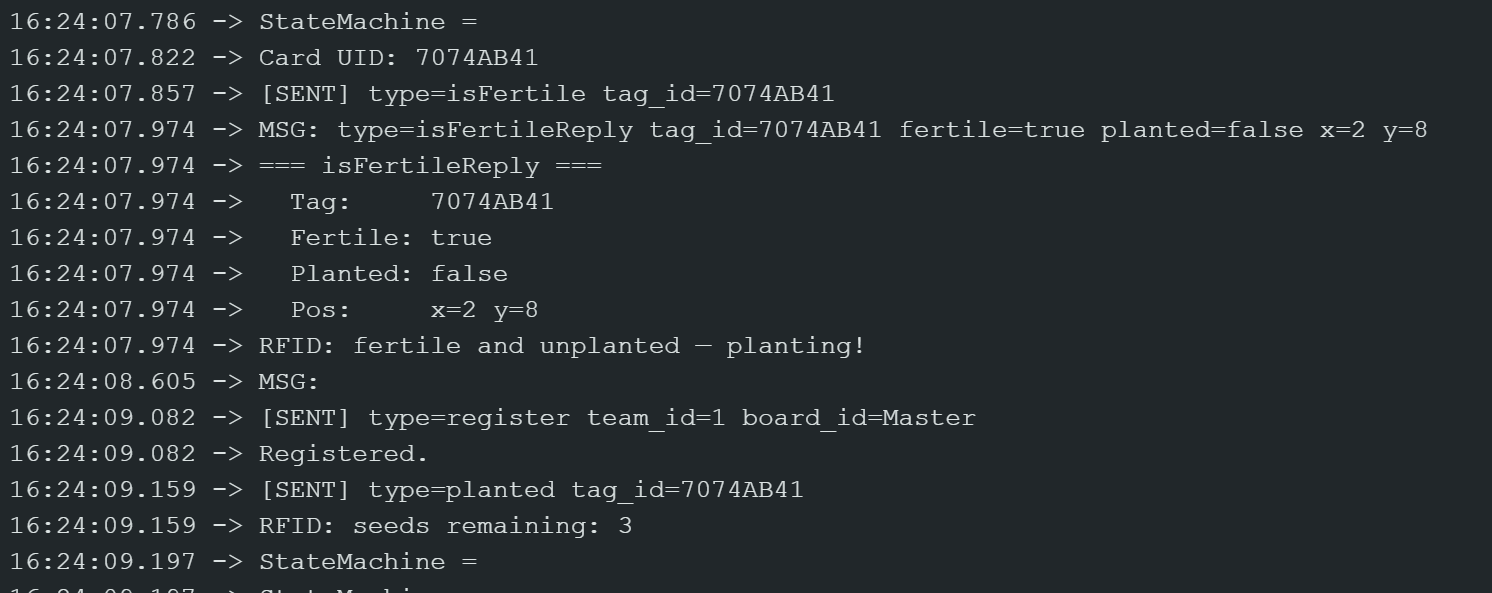
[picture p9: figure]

(a) Serial debug messages about the planting mechanism.

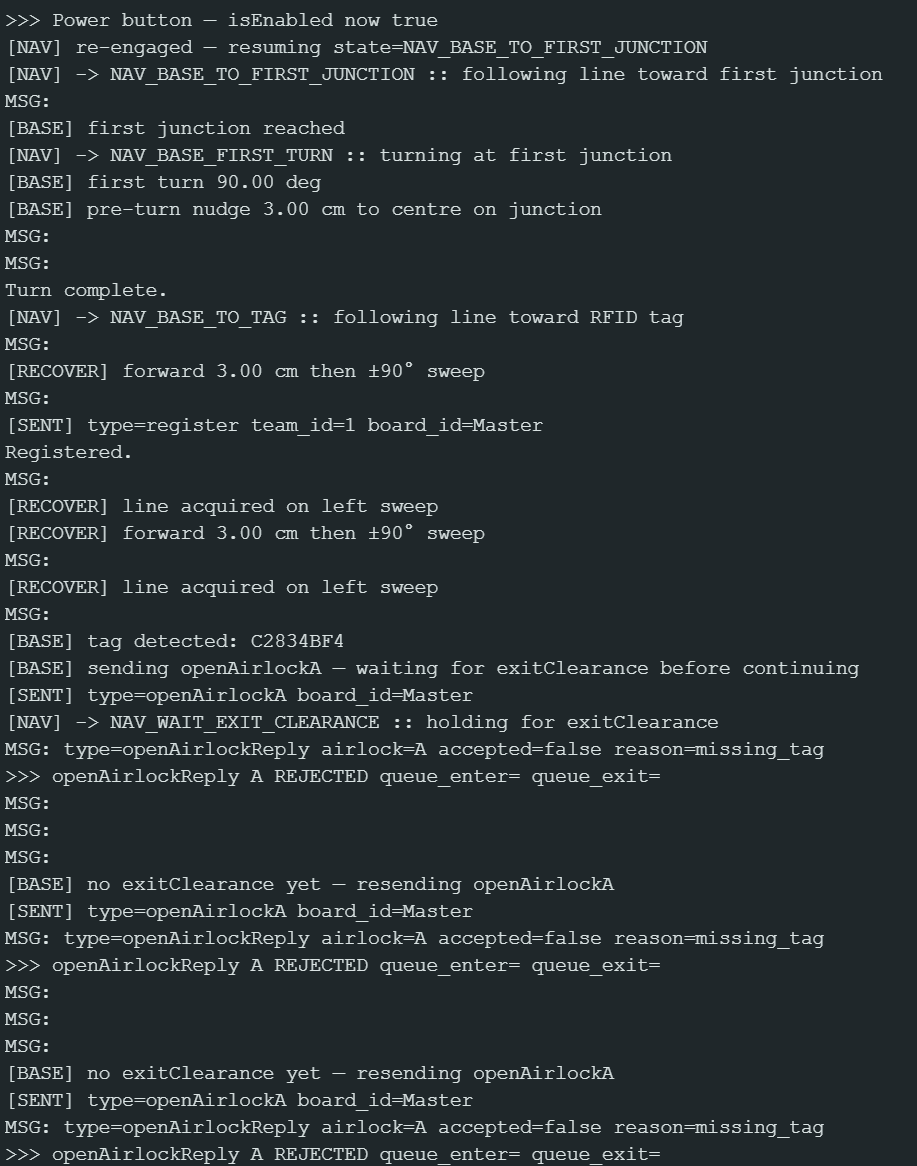
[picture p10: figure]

(a) Serial debug messages for navigating the base and exiting.

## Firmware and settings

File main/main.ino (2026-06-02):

#include <Wire.h>
#include <Servo.h>
#include "MFRC522_I2C.h"
#include <Motoron.h>
#include <LSM6.h>
#include <kvstore_global_api.h>
#include <MiniMessenger.h>
#include "config.h"
#include "globals.h"

// ─────────────────────────────────────────
// Global definitions (extern'd in globals.h)
// ─────────────────────────────────────────
bool  showIR               = false;
bool  showDistance         = false;
bool  showEncoders         = false;
bool  showPitch            = false;
bool  showLDR              = false;
bool  isEnabled            = false;
bool  useStateMachine      = true;    // state machine drives behavior; set false to fall back to legacy rfidLoop + applyMotorEnabled
float lastForwardDistanceCm = 0.0f;   // refreshed by the obstacle check at top of loop()

void setup() {
  Serial.begin(SERIAL_BAUD);
  uint32_t startWait = millis();
  while (!Serial && millis() - startWait < SERIAL_WAIT_MS);

  irSetup();
  distanceSetup();
  Wire.begin();
  Wire1.begin();
  rfidSetup();
  servoSetup();
  motorsSetup();
  encoderSetup();
  wifiSetup();

  pinMode(POWER_BUTTON,    INPUT_PULLUP);
  pinMode(REVIVE_BUTTON_1, INPUT_PULLUP);
  pinMode(REVIVE_BUTTON_2, INPUT_PULLUP);

  Serial.println("\nReady. Commands:");
  Serial.println("  <number>            → turn that many degrees");
  Serial.println("  forward [spd]       → move forward 3s");
  Serial.println("  hop                 → one heading-locked hop");
  Serial.println("  ir / distance       → toggle sensor prints");
  Serial.println("  sensors             → toggle all sensor prints");
  Serial.println("  enc / encreset      → encoder print toggle / zero");
  Serial.println("  c / calib           → recalibrate IR / print calib state");
  Serial.println("  nav                 → toggle state machine");
  Serial.println("  state               → dump navState + position");
  Serial.println("  pos <r> <c> <n|e|s|w>  → set robotPos + facing");
  Serial.println("  tag <r> <c> <u|f|i|p>  → set tagMap cell");
  Serial.println("  target              → print selectNextTarget");
  Serial.println("  astar <r1> <c1> <r2> <c2>  → A* next step");
  Serial.println("  selftest            → run logic assertions");
  Serial.println("  <anything else>     → forward to server");
  delay(1000);
}

// Power button: poll the pin every tick, toggle isEnabled on each press
// (HIGH→LOW edge). 200 ms cooldown prevents bounce-induced double-toggle.
// Not static so blocking helpers (turnDegrees, moveForward, sweepTo) can
// also poll it mid-action — otherwise the kill switch is dead while the bot
// is turning or planting.
void checkPowerButton() {
  static unsigned long lastPressMs = 0;
  static bool wasPressed = false;
  static bool firstCall  = true;
  const bool pressedNow = (digitalRead(POWER_BUTTON) == LOW);

  // Seed wasPressed from the real pin state on the first call so that holding
  // the button at boot doesn't get detected as a fresh press the moment we
  // start polling.
  if (firstCall) {
    wasPressed = pressedNow;
    firstCall = false;
    return;
  }

  if (pressedNow && !wasPressed && (millis() - lastPressMs > 200)) {
    isEnabled = !isEnabled;
    lastPressMs = millis();
    // Give the heartbeat timeout a fresh baseline so the wifi safety check
    // doesn't immediately undo the toggle (only relevant once heartbeats
    // have started arriving).
    extern unsigned long lastHeartbeatMs;
    if (lastHeartbeatMs != 0) lastHeartbeatMs = millis();
    Serial.print(">>> Power button — isEnabled now ");
    Serial.println(isEnabled ? "true" : "false");
  }
  wasPressed = pressedNow;
}

void loop() {
  // ── Forward obstacle / door check ─────────────────────────────────────
  // Three-tier detection (mirrors obstacle_avoid_test):
  //   < CRASH_STOP_CM (4 cm) or OOR-after-close → immediate: enter
  //     NAV_AVOID_OBSTACLE; navAvoidObstacleTick backs up first.
  //   < OBSTACLE_STOP_CM (8 cm), debounced → enter NAV_AVOID_OBSTACLE
  //     in NAV_ARENA_NAV, or stop-and-wait in door / base states.
  //   < OBSTACLE_AVOID_CM (20 cm) → handled inside navArenaTick (soft
  //     mid-hop trigger) and at-tag peek in navAtTagTick.
  // Status is sent exactly once per rising edge.
  static bool prevObstacle    = false;
  static bool prevRawObstacle = false;
  static bool stableObstacle  = false;

  const float distFwd   = getDistanceCM(SENSOR_FORWARD);
  lastForwardDistanceCm = distFwd;

  // OOR persistence: HC-SR04 can return -1 (OOR) below ~2 cm because the
  // echo arrives before the trigger window closes. If we saw something within
  // OBSTACLE_AVOID_CM recently and the sensor just went OOR, treat it as
  // still close (the obstacle is getting closer, not disappearing).
  static unsigned long lastCloseReadingMs = 0;
  if (distFwd >= 0.0f && distFwd < (float)OBSTACLE_AVOID_CM) {
    lastCloseReadingMs = millis();
  }
  const bool oor_persisting = (distFwd < 0.0f &&
                               lastCloseReadingMs != 0 &&
                               millis() - lastCloseReadingMs < (unsigned long)OOR_PERSISTENCE_MS);

  // Crash: reading below CRASH_STOP_CM, or OOR-after-close. No debounce —
  // react on the first tick.
  const bool crashNow = (distFwd >= 0.0f && distFwd < (float)CRASH_STOP_CM) ||
                        oor_persisting;

  // Stop: debounced signal for the 8 cm tier (also catches OOR persistence).
  const bool rawObstacle = (distFwd >= 0.0f && distFwd < (float)OBSTACLE_STOP_CM) ||
                           oor_persisting;

  // 2-consecutive-readings debounce for the stop tier.
  if (rawObstacle != stableObstacle && rawObstacle == prevRawObstacle) {
    stableObstacle = rawObstacle;
  }
  prevRawObstacle = rawObstacle;
  const bool obstacleNow = stableObstacle;

  if (obstacleNow && !prevObstacle) {
    sendStatus("obstacle_stop");
    Serial.println(">>> obstacle in front — holding");
  }
  if (!obstacleNow && prevObstacle) {
    sendStatus("obstacle_cleared");
    Serial.println(">>> obstacle cleared — resuming");
  }

  // Door-retry: resend the open-airlock request while paused at a closed door.
  static unsigned long doorRetryDeadlineMs = 0;
  const bool atClosedDoor = obstacleNow &&
    (navState == NAV_WALL_FOLLOW || navState == NAV_TUNNEL_B_WALL_FOLLOW);
  if (atClosedDoor) {
    if (!prevObstacle) {
      doorRetryDeadlineMs = millis() + DOOR_RETRY_INTERVAL_MS;
    }
    if (millis() >= doorRetryDeadlineMs) {
      if (navState == NAV_WALL_FOLLOW) {
        Serial.println("[BASE] door still closed — resending openAirlockA");
        sendOpenAirlockA();
      } else {
        Serial.println("[BASE] door still closed — resending openAirlockB");
        sendOpenAirlockB();
      }
      doorRetryDeadlineMs = millis() + DOOR_RETRY_INTERVAL_MS;
    }
  }

  prevObstacle = obstacleNow;

  // ── Always-run pass ───────────────────────────────────────────────────
  // WiFi must run so the server can re-enable us. Serial commands must run
  // so debug tools work while disabled. Encoders and diagnostic prints are
  // passive (no motor activity) and useful for bench-testing without the
  // server.
  wifiLoop();
  checkPowerButton();
  handleSerialCommands();
  updateEncoders();
  updateHopHeading();           // no-ops when no hop is active
  readAndPrintIR();
  readAndPrintDistance();
  readAndPrintEncoders();
  readAndPrintPitch();
  readAndPrintLDR();

  // ── Safety gate ───────────────────────────────────────────────────────
  // Skip the body when disabled OR while an obstacle is in front. The
  // disabled path additionally collapses nav state via handleNavDisable
  // so it requires explicit re-engagement. The obstacle path just pauses
  // — navState is preserved and the body resumes as soon as the obstacle
  // clears, which is the door-opening case.
  if (!isEnabled) {
    motoron.setSpeedNow(LEFT_MOTOR,  0);
    motoron.setSpeedNow(RIGHT_MOTOR, 0);
    if (useStateMachine) handleNavDisable();
    delay(10);
    return;
  }
  // ── Obstacle / avoidance gate ────────────────────────────────────────
  // Bypass entirely during revival (intentional contact) and while
  // navAvoidObstacleTick is running (it manages its own motors).
  const bool revivingNow      = useStateMachine &&
    (navState == NAV_REVIVING || navState == NAV_WAIT_REVIVE_REPLY);
  const bool avoidingObstacle = useStateMachine && navState == NAV_AVOID_OBSTACLE;

  if (!revivingNow && !avoidingObstacle) {
    // ── Crash tier (< CRASH_STOP_CM or OOR-after-close): no debounce ──
    // Immediately enter NAV_AVOID_OBSTACLE. The tick function checks
    // lastForwardDistanceCm and backs up before replanning.
    if (crashNow && useStateMachine && navState == NAV_ARENA_NAV) {
      motoron.setSpeedNow(LEFT_MOTOR,  0);
      motoron.setSpeedNow(RIGHT_MOTOR, 0);
      Serial.print("[CRASH] ");
      if (distFwd < 0.0f) Serial.print("OOR-persist");
      else { Serial.print(distFwd, 1); Serial.print(" cm"); }
      Serial.println(" — entering NAV_AVOID_OBSTACLE (crash)");
      lastCloseReadingMs = 0;   // stale after replan+turn; reset so it can't retrigger
      navState = NAV_AVOID_OBSTACLE;
      // Fall through — let navigationUpdate run navAvoidObstacleTick this tick.

    // ── Stop tier (< OBSTACLE_STOP_CM, debounced) ─────────────────────
    } else if (obstacleNow) {
      // In NAV_ARENA_NAV: trigger avoidance rather than a bare stop.
      if (useStateMachine && navState == NAV_ARENA_NAV) {
        motoron.setSpeedNow(LEFT_MOTOR,  0);
        motoron.setSpeedNow(RIGHT_MOTOR, 0);
        Serial.print("[OBSTACLE] "); Serial.print(distFwd, 1);
        Serial.println(" cm — entering NAV_AVOID_OBSTACLE");
        lastCloseReadingMs = 0;
        navState = NAV_AVOID_OBSTACLE;
        // Fall through — let navigationUpdate run navAvoidObstacleTick this tick.

      } else {
        // Door / tunnel / base states: stop-and-wait (existing behaviour).
        motoron.setSpeedNow(LEFT_MOTOR,  0);
        motoron.setSpeedNow(RIGHT_MOTOR, 0);
        if (useStateMachine && navState == NAV_BASE_RETURN) {
          sendStatus("parked_obstacle");
          navState = NAV_PARKED;
        }
        delay(10);
        return;
      }
    }
  }

  // ── Enabled body ──────────────────────────────────────────────────────
  if (useStateMachine) {
    navigationUpdate();
  } else {
    // For testing purposes, in practice not used
    rfidLoop();
    applyMotorEnabled();
  }

  delay(10);
}

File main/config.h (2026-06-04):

#pragma once

// ─────────────────────────────────────────
// Robot State
// ─────────────────────────────────────────
#define SEED_COUNT  5

// ─────────────────────────────────────────
// Servo
// ─────────────────────────────────────────
#define SERVO_PIN       9
#define SERVO_MIN_US    750
#define SERVO_MAX_US    2250
#define MIN_ANGLE       60    // get seed
#define MAX_ANGLE       180   // release seed
#define STEP_DELAY      5     // ms per degree during sweep

// ─────────────────────────────────────────
// Motors
// ─────────────────────────────────────────
#define LEFT_MOTOR      1
#define RIGHT_MOTOR     2
#define MOTORON_ADDRESS 16
#define MOTOR_VOLTAGE   6     // rated motor voltage
#define INPUT_VOLTAGE   7.2     // actual supply voltage
// Pivot turn speeds. The "forward" wheel goes forward, the "backward" wheel
// goes backward; we keep the backward wheel slower because the backward-going
// side slips more due to weight transfer. Split by direction so left- and
// right-turn behaviour can be tuned independently — the two motors aren't
// always equally strong, so symmetric speed commands can produce asymmetric
// physical turns. RIGHT_* tunes a clockwise pivot, LEFT_* tunes CCW.
#define RIGHT_TURN_FORWARD_SPEED    600     // left wheel during right turn
#define RIGHT_TURN_BACKWARD_SPEED   450     // right wheel during right turn
#define LEFT_TURN_FORWARD_SPEED     600     // right wheel during left turn — tune to match right turn
#define LEFT_TURN_BACKWARD_SPEED    450     // left wheel during left turn — tune to match right turn
// Per-direction "stop early" trim, in degrees, subtracted from the target
// magnitude inside turnDegrees(). If one direction over-rotates, raise its
// trim so the gyro integrator hits the break point sooner.
// Values match grid_nav_no_line_test: right turn coasts farther on this bot.
#define RIGHT_TURN_TRIM_DEG         5.0f
#define LEFT_TURN_TRIM_DEG          0.0f
#define FORWARD_SPEED         400     // Default forward speed

// ─────────────────────────────────────────
// IMU
// ─────────────────────────────────────────
#define GYRO_CALIB_SAMPLES  500
#define GYRO_SENS           0.00875f  // dps/LSB for ±250 dps range
#define HEADING_KP          3.0f      // proportional gain for hop-heading correction

// ─────────────────────────────────────────
// IR Sensor Array
// ─────────────────────────────────────────
#define IR_CTRL_PIN         12
#define IR_SENSOR_COUNT     9
#define IR_TIMEOUT_US       2500      // max reflection time (µs)
#define IR_MIN_LINE_SUM     200       // minimum sum to trust position reading

static const int IR_SENSOR_PINS[IR_SENSOR_COUNT] = {30, 31, 32, 33, 34, 35, 36, 37, 38};

// ─────────────────────────────────────────
// Ultrasonic
// ─────────────────────────────────────────
#define RIGHT_TRIG_PIN      40
#define RIGHT_ECHO_PIN      41
#define LEFT_TRIG_PIN       42
#define LEFT_ECHO_PIN       43
#define FORWARD_TRIG_PIN    44
#define FORWARD_ECHO_PIN    45
#define ULTRASONIC_TIMEOUT  30000     // pulseIn timeout (µs), ~5m max range

// ─────────────────────────────────────────
// LDR (light-dependent resistor, analog read 0..1023)
// ─────────────────────────────────────────
#define LDR_PIN             A7

// ─────────────────────────────────────────
// RFID
// ─────────────────────────────────────────
#define RFID_I2C_ADDRESS    0x28
#define RFID_RESET_PIN      255       // not used (I2C mode)

// ─────────────────────────────────────────
// Serial
// ─────────────────────────────────────────
#define SERIAL_BAUD         115200
#define SERIAL_WAIT_MS      3000      // max wait for Serial to connect on startup

// ─────────────────────────────────────────
// WiFi / Messaging
// ─────────────────────────────────────────
#define HEARTBEAT_TIMEOUT_MS    1000    // disable motors if no heartbeat within this window
#define REGISTER_INTERVAL_MS    10000   // how often to re-register with server

// ─────────────────────────────────────────
// Status LED (RGB)
// ─────────────────────────────────────────
#define LED_R   48
#define LED_G   49
#define LED_BLINK_INTERVAL_MS   500     // blink rate when disabled

// ─────────────────────────────────────────
// Buttons
// ─────────────────────────────────────────
#define POWER_BUTTON      17
#define REVIVE_BUTTON_1   52
#define REVIVE_BUTTON_2   53
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

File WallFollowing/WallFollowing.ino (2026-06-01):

#include <Wire.h>
#include <Motoron.h>

// ── Hardware ────────────────────────────────────────────────────────────────
const int TRIG_PIN = 42;
const int ECHO_PIN = 43;

MotoronI2C motoron(16, &Wire1);

// ── Tuning ──────────────────────────────────────────────────────────────────
const float TARGET_CM       = 15.0;   // desired gap to wall
const float Kp              = 25.0;  // proportional gain
const float Kd              = 120.0;  // derivative gain — high to damp overshoot
const int   BASE_SPEED      = 350;   // straight-line motor speed (–800 … 800)
const int   MAX_CORRECTION  = 600;   // clamp so we never stall a motor
const int   SENSOR_DELAY_MS = 60;    // HC-SR04 minimum cycle time
const float EMA_ALPHA       = 0.4;   // EMA smoothing — higher = less derivative lag

// ── State ───────────────────────────────────────────────────────────────────
float previousDistance = TARGET_CM;
float smoothedDistance = TARGET_CM;
unsigned long previousTime = 0;

// ── Sensor ──────────────────────────────────────────────────────────────────
float singleRead() {
  digitalWrite(TRIG_PIN, LOW);
  delayMicroseconds(2);
  digitalWrite(TRIG_PIN, HIGH);
  delayMicroseconds(10);
  digitalWrite(TRIG_PIN, LOW);

  long duration = pulseIn(ECHO_PIN, HIGH, 30000);  // 30ms timeout
  if (duration == 0) return -1.0;
  return duration / 58.0;
}

float medianOfThree(float a, float b, float c) {
  if (a > b) { float t = a; a = b; b = t; }
  if (b > c) { float t = b; b = c; c = t; }
  if (a > b) { float t = a; a = b; b = t; }
  return b;
}

float getDistanceCM() {
  float a = singleRead(); delay(10);
  float b = singleRead(); delay(10);
  float c = singleRead();

  // If all failed, return invalid
  if (a < 0 && b < 0 && c < 0) return -1.0;

  // Replace any failed reading with a valid neighbour
  if (a < 0) a = (b > 0) ? b : c;
  if (b < 0) b = (a > 0) ? a : c;
  if (c < 0) c = (a > 0) ? a : b;

  return medianOfThree(a, b, c);
}

// ── Motor helpers ────────────────────────────────────────────────────────────
int clampSpeed(int speed) {
  return constrain(speed, -800, 800);
}

void setMotors(int left, int right) {
  motoron.setSpeedNow(1, clampSpeed(left));
  motoron.setSpeedNow(2, clampSpeed(right));
}

// ── Setup ────────────────────────────────────────────────────────────────────
void setup() {
  Serial.begin(115200);
  while (!Serial);

  pinMode(TRIG_PIN, OUTPUT);
  pinMode(ECHO_PIN, INPUT);

  Wire1.begin();
  motoron.reinitialize();
  motoron.disableCommandTimeout();
  motoron.clearResetFlag();

  previousTime = millis();
  Serial.println("Wall follower ready.");
}

// ── Main loop ────────────────────────────────────────────────────────────────
void loop() {
  float raw = getDistanceCM();

  // Skip bad readings — hold previous correction rather than jerking
  if (raw < 0) {
    Serial.println("Sensor: out of range, holding course");
    delay(SENSOR_DELAY_MS);
    return;
  }

  // EMA: smoothed = α·raw + (1−α)·smoothed
  smoothedDistance = EMA_ALPHA * raw + (1.0 - EMA_ALPHA) * smoothedDistance;

  unsigned long now = millis();
  float dt = (now - previousTime) / 1000.0;
  if (dt <= 0) dt = SENSOR_DELAY_MS / 1000.0;  // guard against zero

  // ── PD controller ───────────────────────────────────────────────────────
  float error      = smoothedDistance - TARGET_CM;           // +ve → too far, –ve → too close
  float dError     = (smoothedDistance - previousDistance) / dt; // +ve → drifting away, –ve → closing
  float correction = (Kp * error) + (Kd * dError);
  correction = constrain(correction, -MAX_CORRECTION, MAX_CORRECTION);

  // ── Differential steering ───────────────────────────────────────────────
  // +error → too far from wall → steer toward it
  int leftSpeed  = BASE_SPEED - (int)correction;
  int rightSpeed = BASE_SPEED + (int)correction;
  setMotors(leftSpeed, rightSpeed);

  // ── Debug ────────────────────────────────────────────────────────────────
  Serial.print("raw=");      Serial.print(raw, 1);
  Serial.print("  smooth="); Serial.print(smoothedDistance, 1);
  Serial.print("  err=");    Serial.print(error, 1);
  Serial.print("  dErr=");   Serial.print(dError, 1);
  Serial.print("  corr=");   Serial.print((int)correction);
  Serial.print("  L=");      Serial.print(leftSpeed);
  Serial.print("  R=");      Serial.println(rightSpeed);

  previousDistance = smoothedDistance;
  previousTime     = now;

  delay(SENSOR_DELAY_MS);
}

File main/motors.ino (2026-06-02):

// ─────────────────────────────────────────
// Motors / IMU
// ─────────────────────────────────────────
LSM6 imu;
MotoronI2C motoron(MOTORON_ADDRESS, &Wire1);
float gyroZOffset = 0;

// ─────────────────────────────────────────
// Encoders (quadrature, one per rear wheel, interrupt-driven on Giga).
// Back-left  uses pins 22/23. Back-right uses pins 24/25.
// ─────────────────────────────────────────
volatile long encBL = 0;
volatile long encBR = 0;

static volatile bool lastBL_A = false, lastBL_B = false;
static volatile bool lastBR_A = false, lastBR_B = false;

// Quadrature decoders: one ISR per channel. A-edge sign is the inverse of
// B-edge sign for the same direction — that's what gives 4x decoding.
static void isr_BL_A() { bool a = digitalRead(ENC_BL_A), b = digitalRead(ENC_BL_B); if (a != lastBL_A) { encBL += (a == b) ?  1 : -1; lastBL_A = a; } }
static void isr_BL_B() { bool a = digitalRead(ENC_BL_A), b = digitalRead(ENC_BL_B); if (b != lastBL_B) { encBL += (a == b) ? -1 :  1; lastBL_B = b; } }
static void isr_BR_A() { bool a = digitalRead(ENC_BR_A), b = digitalRead(ENC_BR_B); if (a != lastBR_A) { encBR += (a == b) ? -1 :  1; lastBR_A = a; } }
static void isr_BR_B() { bool a = digitalRead(ENC_BR_A), b = digitalRead(ENC_BR_B); if (b != lastBR_B) { encBR += (a == b) ?  1 : -1; lastBR_B = b; } }

void encoderSetup() {
  pinMode(ENC_BL_A, INPUT_PULLUP); pinMode(ENC_BL_B, INPUT_PULLUP);
  pinMode(ENC_BR_A, INPUT_PULLUP); pinMode(ENC_BR_B, INPUT_PULLUP);

  // Seed last-state from current pin reads so the first edge isn't misread.
  lastBL_A = digitalRead(ENC_BL_A); lastBL_B = digitalRead(ENC_BL_B);
  lastBR_A = digitalRead(ENC_BR_A); lastBR_B = digitalRead(ENC_BR_B);

  attachInterrupt(digitalPinToInterrupt(ENC_BL_A), isr_BL_A, CHANGE);
  attachInterrupt(digitalPinToInterrupt(ENC_BL_B), isr_BL_B, CHANGE);
  attachInterrupt(digitalPinToInterrupt(ENC_BR_A), isr_BR_A, CHANGE);
  attachInterrupt(digitalPinToInterrupt(ENC_BR_B), isr_BR_B, CHANGE);

  Serial.println("Encoders ready (interrupt-driven, 4x quadrature, 1 per side).");

  // Restore previously-locked ticks/cm if we have one saved. If not, the
  // in-run calibration path takes over and saves on lock.
  if (!loadCalibFromKV()) {
    Serial.print("No saved encoder calib; using fallback ticks_per_cm=");
    Serial.println(calibTicksPerCm);
  }
}

// No-op under the current interrupt-driven encoder design — counters are
// updated by ISRs. Kept so the main-loop call site is uniform and so a
// future swap to polling only needs a body change here.
void updateEncoders() { }

// Pitch debug print — used to identify which accelerometer axis points
// forward on this build so the ramp feed-forward picks the right axis & sign.
// Prints both possible pitch computations; whichever swings most on a ramp
// is the forward axis. ±sign on the ramp tells us the sign convention.
void readAndPrintPitch() {
  if (!showPitch) return;
  static unsigned long lastPrintMs = 0;
  if (millis() - lastPrintMs < 200) return;
  lastPrintMs = millis();
  imu.read();
  float pitchX = atan2((float)imu.a.x, (float)imu.a.z) * RAD_TO_DEG;
  float pitchY = atan2((float)imu.a.y, (float)imu.a.z) * RAD_TO_DEG;
  Serial.print("accel ax="); Serial.print(imu.a.x);
  Serial.print(" ay=");      Serial.print(imu.a.y);
  Serial.print(" az=");      Serial.print(imu.a.z);
  Serial.print("  pitchX="); Serial.print(pitchX, 1);
  Serial.print("deg pitchY="); Serial.print(pitchY, 1);
  Serial.println("deg");
}

// Diagnostic print, rate-limited to ~5 Hz so the serial monitor stays readable.
void readAndPrintEncoders() {
  if (!showEncoders) return;
  static unsigned long lastPrintMs = 0;
  if (millis() - lastPrintMs < 200) return;
  lastPrintMs = millis();
  Serial.print("enc BL="); Serial.print(encBL);
  Serial.print(" BR=");    Serial.println(encBR);
}

long leftTicks()     { return encBL; }
long rightTicks()    { return encBR; }
long straightTicks() { return (leftTicks() + rightTicks()) / 2; }

void encoderResetHop() {
  noInterrupts();
  encBL = encBR = 0;
  interrupts();
}

// ─────────────────────────────────────────
// Self-calibrating ticks/cm
// Locks after CALIB_MIN_SAMPLES accepted straight-hop samples.
// ─────────────────────────────────────────
float calibTicksPerCm = TICKS_PER_CM_FALLBACK;
bool  calibLocked     = false;
int   calibSamples    = 0;
float calibSum        = 0;

static const char* CALIB_KV_KEY = "/kv/calib_tpc";

// Persist the locked ticks/cm so the robot doesn't recalibrate from scratch
// on every boot. Mirrors the IR sensor's kvstore pattern in ir_sensor.ino.
void saveCalibToKV() {
  int rc = kv_set(CALIB_KV_KEY, &calibTicksPerCm, sizeof(calibTicksPerCm), 0);
  if (rc == 0) {
    Serial.print("Encoder calib saved to KV: ticks_per_cm=");
    Serial.println(calibTicksPerCm);
  } else {
    Serial.print("Encoder calib KV save FAILED, rc=");
    Serial.println(rc);
  }
}

// Try to restore a previously-locked value. Returns true on success and sets
// calibTicksPerCm + calibLocked. Sanity-checks the loaded value so a corrupt
// KV entry falls back to the in-run calibration path instead of poisoning
// dead reckoning with garbage.
bool loadCalibFromKV() {
  float    saved;
  size_t   actualSize = 0;
  int rc = kv_get(CALIB_KV_KEY, &saved, sizeof(saved), &actualSize);
  if (rc != 0)                    return false;
  if (actualSize != sizeof(float)) return false;
  if (saved < 0.1f || saved > 1000.0f) {
    Serial.print("Encoder calib KV entry out of range (");
    Serial.print(saved);
    Serial.println("); ignoring.");
    return false;
  }
  calibTicksPerCm = saved;
  calibLocked     = true;
  Serial.print("Encoder calib loaded from KV: ticks_per_cm=");
  Serial.println(calibTicksPerCm);
  return true;
}

// Erase the saved value and reset the accumulator so the next run
// recalibrates from scratch. Used by the `recalib` serial command.
void clearCalibKV() {
  int rc = kv_remove(CALIB_KV_KEY);
  calibLocked     = false;
  calibSamples    = 0;
  calibSum        = 0.0f;
  calibTicksPerCm = TICKS_PER_CM_FALLBACK;
  Serial.print("Encoder calib reset (KV rc=");
  Serial.print(rc);
  Serial.print(", in-memory ticks_per_cm=");
  Serial.print(calibTicksPerCm);
  Serial.println(")");
}

float hopDistanceCm() {
  return (float)straightTicks() / calibTicksPerCm;
}

bool nearNextNode() {
  return hopDistanceCm() >= GRID_SPACING_CM * NODE_ARRIVAL_FRACTION;
}
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

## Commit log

2026-04-28 servo and RFID
2026-04-29 save calibration
2026-05-13 Add servo motor control and feedback functionality
    Implement servo motor control with feedback reading.
2026-05-14 Finished buttons
2026-05-27 fix bugs and testing
    [commands.ino, main.ino, motors.ino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]
2026-05-28 line following bug fixes
    [commands.ino, config.h, distance.ino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]
2026-05-29 Revise junction handling and add path planning flowchart
    Updated the junction handling section and added prospective flowchart for path planning.
2026-05-29 Fix formatting issues in flowcharts documentation
2026-05-29 Fix formatting for flowchart in flowcharts.md
2026-05-29 Update path planning flowchart in docs
    Revised the flowchart for path planning in the second half of the arena, updating the logic and flow of operations.
2026-05-29 Reorder flowchart steps for clarity
2026-05-29 Fix flowchart formatting in flowcharts.md
2026-05-29 Remove redundant planting function call from flowchart
2026-05-29 Clarify flowchart step for orientation check
2026-05-29 flowcharts fixed
